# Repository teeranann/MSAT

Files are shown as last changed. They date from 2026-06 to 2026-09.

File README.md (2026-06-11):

# MSAT — Multi-Sensor Automatic Titrator

A low-cost, **ESP32-based open-hardware automatic acid–base titrator** with
gravimetric titrant delivery. It records **pH, electrical conductivity (EC),
colour change (ΔE), and temperature** simultaneously and in real time, serves a
live **WiFi dashboard**, and logs every run to an SD card. A companion desktop
**data analyzer** finds equivalence points (1st/2nd derivative + inflection
trendlines) and estimates titration enthalpy, and a **sync tool** copies runs
from the device to a PC.

> Copyright © 2026 **Burapha University**. Inventor/developer: **Teeranan Nongnual**.
> Co-inventors: **Nuttawisit Yasarawan, Pichamon Jittaviriyapong, Kanoksak Saelee, Akapong Suwattanamala, Supranee Kaewpirom, Takat Benjalersyarnon**.
> **Petty Patent pending — Application No. 2603001145** (filed 2026‑05‑12).
> Open source: Apache‑2.0 (code), CERN‑OHL‑S v2 (hardware), CC BY 4.0 (docs) — see [License](#license).

---

## Why MSAT?

Conventional manual burettes give discrete points and rely on subjective visual
endpoints. MSAT delivers titrant by mass (high precision), captures four sensor
channels continuously, and determines endpoints objectively across mono- and
polyprotic acid–base systems — at a fraction of the cost of commercial
autotitrators, suitable for teaching and research labs.

## Repository layout

| Folder | What it is |
|---|---|
| [`firmware/`](firmware/) | ESP32 Arduino firmware (`.ino`) — sensor acquisition, filtering, WiFi dashboard, SD logging |
| [`analyzer/`](analyzer/) | Python desktop app — load/analyze runs, EP detection, ΔT, live monitor |
| [`sync/`](sync/) | Windows + Git Bash tool — download runs from the device, clean up, protect folder |
| [`hardware/`](hardware/) | Wiring diagram, Fritzing sketch, component list |
| [`sample-data/`](sample-data/) | Example titration runs (one per acid) |
| [`docs/`](docs/) | Images and additional documentation |

## Quick start

1. **Build the device** — see [`hardware/`](hardware/) for wiring (ESP32 + ADS1115 pH,
   RS‑485/Modbus EC meter, GY‑33 colour, DS18B20 temperature, HX711 load cell, relay pump).
2. **Flash the firmware** — open [`firmware/msat-firmware/msat-firmware.ino`](firmware/),
   set your WiFi name/password (lines marked `EDIT ME`), install the required
   libraries, and upload. See [`firmware/README.md`](firmware/README.md).
3. **Open the dashboard** — browse to the device IP (default `192.168.1.200`) to
   start/monitor a titration live.
4. **Sync the data** — run [`sync/msat-sync.bat`](sync/) to copy runs to your PC.
5. **Analyze** — `pip install -r analyzer/requirements.txt` then
   `python analyzer/msat-datanal.py`. See [`analyzer/README.md`](analyzer/README.md).

## Key features

- **4 sensors in one run:** pH (ADS1115), EC (Modbus meter), colour ΔE (CIELAB/RGB), temperature (DS18B20)
- **Gravimetric titrant delivery** via load cell — endpoint by volume *or* mass
- **Real-time WiFi dashboard** (WebSocket) + on-device LCD
- **Auto-stop** by weight loss or time; SD logging of every run
- **Robust signal conditioning** (median + EMA + anomaly rejection) — clean curves, sharp inflections
- **Analyzer:** equivalence points (derivative + inflection trendlines), ΔT/enthalpy, glitch despike, live monitor via device WebSocket, batch export (PNG/TIFF/SVG/PDF) and config save/restore
- **Sync tool:** fast WiFi download, "clean up space" on the device, read-only folder protection

## License

This project is **open source / open hardware**:

- **Software** (firmware, analyzer, sync): **Apache License 2.0** — see [`LICENSE`](LICENSE)
- **Hardware** design files (schematic, wiring, BOM): **CERN‑OHL‑S v2** — see [`LICENSE-hardware`](LICENSE-hardware)
- **Documentation, images, sample data:** **CC BY 4.0**

You may **use, study, modify, distribute, and build upon** this work, **including for
commercial purposes**, under the terms of the applicable license (attribution required;
hardware derivatives must stay open under CERN‑OHL‑S). The petty patent
(Application No. 2603001145, Burapha University) is licensed under the patent grants of
these licenses. See [`NOTICE`](NOTICE).

## Citation

If you use MSAT in academic work, please cite it — see [`CITATION.cff`](CITATION.cff)
(a related manuscript is in preparation; cite the paper too once published).

## Author

**Teeranan Nongnual**<br>
Department of Chemistry, Faculty of Science, Burapha University, Thailand

## Funding

Burapha University (BUU) and Thailand Science Research and Innovation (TSRI).

## Acknowledgements

This software was developed with support from a research grant by Burapha
University and Thailand Science Research and Innovation (TSRI).

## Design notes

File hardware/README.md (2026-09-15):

# MSAT Hardware

Wiring and component information for building the MSAT device.

## Files
- `wiring/WIRING.md` — as-built connection table (power rails, level converter, pins) + part download links
- `wiring/msat-wiring.yml` — **WireViz source of truth** (pin-by-pin harness spec)
- `wiring/msat-wiring.html` — interactive harness diagram + BOM (open in browser)
- `wiring/msat-wiring.svg` / `.png` — rendered harness diagram (paper-grade)
- `wiring/msat-wiring.bom.tsv` — bill of materials (drops into Excel)
- `wiring/msat-wiring-schematic.svg` — high-level block diagram (overview figure)
- `wiring/msat-wiring-components.xlsx` — full wiring list and 30-line purchased BOM (same as Supplementary Tables S1 and S2)
- `wiring/msat-wiring.fzz` — Fritzing breadboard/schematic sketch (work-in-progress)
- `wiring/fritzing-parts/*.fzpz` — custom Fritzing parts
- `3d-print/msat-probe-lid.stl` — probe-mounting lid for the titration beaker (PETG)
- `3d-print/README.md` — print settings and material notes

To re-render the harness after editing the YAML:
```
pip install wireviz   # plus a system install of Graphviz (graphviz.org / winget install Graphviz.Graphviz)
wireviz wiring/msat-wiring.yml
```

## Main components
| Subsystem | Part | Interface |
|---|---|---|
| MCU | ESP32‑WROOM dev board | — |
| Power | 12 V / 5 A supply, LM2596 #1 (5 V bus), LM2596 #2 (pump, ~7.5 V) | — |
| pH | E‑201‑C electrode + analog interface board → ADS1115 16‑bit ADC (5 V) | I²C (0x48) via LLC‑4CH‑I2C level converter |
| EC | MI‑Water‑EC485 platinum‑black electrode + transmitter (12 V) | RS‑485 / Modbus via MAX485 |
| Colour | TCS34725 breakout (3.3 V) | I²C (0x29) |
| Temperature | DS18B20 probe | 1‑Wire (GPIO4) |
| Titrant mass | 200 g load cell + HX711 | GPIO25/26 |
| Pump | 12 V / 3 W peristaltic pump, relay‑switched | GPIO13 |
| Clock | DS3231 RTC (3.3 V) | I²C (0x68) |
| Display | 16×2 LCD, PCF8574 backpack (5 V) | I²C (0x27) |
| Storage | microSD | SPI (CS GPIO5) |

See [`../firmware/README.md`](../firmware/README.md) for the full pin map and
flashing notes (mind the GPIO2/GPIO15 strapping pins).

## Calibration
- **pH:** three‑point (pH 4.01 / 6.86 / 9.18 buffers, as stored in the firmware)
- **EC:** KCl standards across the working range
- **Load cell:** known‑mass calibration

---
Hardware design © 2026 Burapha University · CERN‑OHL‑S v2 · Patent pending No. 2603001145

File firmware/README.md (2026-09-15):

# MSAT Firmware (ESP32)

Arduino firmware for the MSAT device. Reads pH / EC / colour / temperature /
load cell, runs the titration state machine (IDLE → PENDING → RUNNING →
RINSING / REC), serves a WiFi dashboard + WebSocket telemetry, and logs every
run to the SD card.

## Board & toolchain
- **Board:** ESP32 (ESP32‑WROOM, e.g. ESP32‑D0WD‑V3)
- **Arduino‑ESP32 core** 3.x, Arduino IDE or arduino‑cli

## Required libraries (Library Manager)
- ESPAsyncWebServer + AsyncTCP (ESP32Async fork for core 3.x)
- Adafruit ADS1X15 (pH ADC)
- Adafruit TCS34725 (colour) *(GY‑33/TCS34725)*
- DallasTemperature + OneWire (DS18B20)
- HX711 (load cell)
- ModbusMaster (RS‑485 EC meter)
- RTClib (DS3231)
- LiquidCrystal_I2C (16×2 LCD)

## Pin map
| Function | Pin | Notes |
|---|---|---|
| I²C SDA / SCL | 32 / 33 | ADS1115 (pH 0x48, 5 V, through a 3.3 V ↔ 5 V level converter), TCS34725 (0x29), RTC (0x68), LCD (0x27) |
| RS‑485 DE/RE, RX, TX | 2, 16, 17 | EC meter (Modbus) — **GPIO2 is a strapping pin** |
| Load cell DOUT / SCK | 25 / 26 | HX711 |
| DS18B20 (1‑Wire) | 4 | temperature |
| SD card CS | 5 | SPI (VSPI) |
| Relay (pump) | 13 | titrant delivery |
| Buttons 1 / 2 / 3 | 27 / 14 / 15 | **GPIO15 is a strapping pin** |

> ⚠️ **Flashing:** GPIO2 and GPIO15 are ESP32 strapping pins. If wires are
> attached there during upload, flashing can fail — **disconnect them while
> flashing**, then reconnect.

## Configure before flashing
Edit the lines marked `EDIT ME` near the top of
`msat-firmware/msat-firmware.ino`:
```cpp
const char* ssid     = "YOUR_WIFI_SSID";       // 2.4 GHz network
const char* password = "YOUR_WIFI_PASSWORD";
#define ADMIN_PASSWORD "CHANGE_ME_BEFORE_USE"
```
The device uses a **static IP `192.168.1.200`** (gateway `192.168.1.1`) — change
`local_IP`/`gateway` if your network differs. After boot, open
`http://192.168.1.200/` for the dashboard.

> **Before you flash.** `ssid`, `password` and `ADMIN_PASSWORD` ship as placeholders and must be
> set to your own values. Do not commit real credentials: keep your edited copy local, or move the
> three values into a `secrets.h` that is listed in `.gitignore`.

## Sensor calibration
pH (3‑point: 4.01 / 6.86 / 9.18 buffers), EC (KCl standards), and load cell are calibrated via the
device/analyzer; see [`../hardware/`](../hardware/).

---
Copyright © 2026 Burapha University · Apache-2.0 · Patent pending No. 2603001145

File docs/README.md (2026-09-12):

# Documentation & images

Add device photos, dashboard screenshots, and example analyzed plots to
`images/` and reference them from the top‑level `README.md`.

Suggested images to add before publishing:
- `images/device.jpg` — the assembled MSAT instrument
- `images/dashboard.png` — live WiFi dashboard during a run
- `images/analyzer.png` — Data Analyzer with a titration + equivalence point
- `images/curve-example.png` — pH/EC/ΔE/T 4‑panel result

---
© 2026 Burapha University · CC BY 4.0

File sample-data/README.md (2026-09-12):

# Sample data

One representative titration run per acid (NaOH titrant). Load any `.txt` in
the Analyzer (`analyzer/`).

**These nine files are the exact runs the figures in the accompanying manuscript
were produced from**, so every published trace can be regenerated from this
folder.

| Acid | Run file | Figure panel source |
|---|---|---|
| KHP | `20260519_095745_KHP-3.txt` | `XO-20260519_095745_KHP-3` |
| HCl | `20260524_222410_HCl-12.txt` | `XO-20260524_222410_HCl-12` |
| H₂SO₄ | `20260524_224718_H2SO4-11.txt` | `XO-20260524_224718_H2SO4-11` |
| Oxalic | `20260525_145642_oxalic-12.txt` | `XO-20260525_145642_oxalic-12` |
| Phosphoric | `20260524_220156_phosphoric-15.txt` | `XO-20260524_220156_phosphoric-15` |
| Malic | `20260525_141012_malic-12.txt` | `XO-20260525_141012_malic-12` |
| Citric | `20260519_162855_Citric-12.txt` | `XO-20260519_162855_Citric-12` |
| Succinic | `20260521_102418_Succinic-17.txt` | `XO-20260521_102418_Succinic-17` |
| Benzoic | `20260521_154031_Benzoic-13.txt` | `XO-20260521_154031_Benzoic-13` |

All nine were recorded on the released firmware at a logging interval of
500 ms (2 Hz) and use the 13-column schema below.

## File format (CSV)
Header row, then one row per sample (500 ms apart):
```
SampleIndex,Timestamp,Temp,pH,Volt,EC,Weight,Weightloss,R,G,B,C,RelayStatus
```
| Column | Meaning | Unit |
|---|---|---|
| Temp | temperature | °C |
| pH | electrode pH | — |
| Volt | pH electrode voltage (amplified module output) | V |
| EC | conductivity | µS/cm |
| Weight / Weightloss | balance reading / titrant delivered | g |
| R,G,B,C | colour sensor channels | raw counts |
| RelayStatus | pump ON/OFF | — |

`Weightloss` (g) is the titrant axis (≈ mL at density 1.0).

Mass is recorded to two decimals, so the recording quantum is 10 mg; the
short-term repeatability of the mass channel in these runs is 5–6 mg.

pH is obtained by piecewise-linear interpolation between the three calibration
buffers (4.01 / 6.86 / 9.18), with linear extrapolation of the terminal segment
outside that range and a hard clamp to 0–14. Values above pH 9.18 are therefore
extrapolated.

## Acids included
KHP, HCl, H₂SO₄, oxalic, phosphoric, malic, citric, succinic, benzoic.

---
Data © 2026 Burapha University · CC BY 4.0

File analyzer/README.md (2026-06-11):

# MSAT Data Analyzer

Desktop app (Python + Tkinter/ttkbootstrap + matplotlib) to analyze MSAT runs.

## Install & run
```bash
pip install -r requirements.txt
python msat-datanal.py
```
Python 3.10+ recommended. `tkinterdnd2` is optional (drag‑and‑drop);
`websocket-client` enables the Live Monitor.

## What it does
- **Load a run** (`.txt`) via *Local File* or drag‑and‑drop; one‑shot load.
- **Derived curves:** pH (2‑point calibrated), colour ΔE (CIELAB or RGB),
  EC (auto µS/mS), temperature — plus 1st/2nd derivatives.
- **Equivalence points:** per‑sensor strategy (1st deriv. / 2nd deriv. /
  inflection trendlines); ΔT (enthalpy proxy).
- **Data processing:** auto "hiccup" despike (X‑axis glitch removal),
  Savitzky–Golay smoothing, click‑to‑delete a point, manual exclude.
- **Display:** per‑axis ranges, tick interval, point size/font, X in mL/mol/sec/g.
- **Live Monitor:** *Check MSAT* → *Live Monitor* listens to the device
  WebSocket (`ws://192.168.1.200/ws`) and plots the run in real time
  (seamless across multiple runs; UI locks until you Stop or load a file).
- **Export:** PNG/TIFF/SVG/PDF (filenames prefixed `-`) plus a
  `-<name>-config.txt` sidecar that restores all settings when the file is
  reopened.

## Notes
- Device default IP is `192.168.1.200` (edit `self.msat_ip` if changed).
- The high‑resolution record is the device SD file; Live Monitor is a coarse
  real‑time preview — sync the full file afterwards for detailed analysis.

---
Copyright © 2026 Burapha University · Apache-2.0 · Patent pending No. 2603001145

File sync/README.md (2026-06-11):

# MSAT Sync

Download titration runs from the MSAT device to a PC over WiFi, with optional
cleanup and folder protection. Windows front‑end (`msat-sync.bat`) drives the
worker (`msat-sync.sh`, runs under **Git Bash**).

## Requirements
- Windows + [Git for Windows](https://git-scm.com/download/win) (provides Git Bash)
- PC on the same WiFi as the device (default `192.168.1.200`)

## Use
Double‑click **`msat-sync.bat`** and pick from the menu:
```
[1] Sync files MSAT -> PC          (download new/updated runs)
[2] Clean up space on MSAT         (delete files older than N days)
[4] PROTECT MSAT-Output folder     (block accidental delete/rename)
[5] UNPROTECT MSAT-Output folder   (restore normal permissions)
[Q] Quit
```
- **Sync** writes runs into `MSAT-Output/` next to the script.
- **Cleanup** only deletes device files that are already backed up locally
  (size check) and older than the chosen days; you must type `DELETE` to confirm.
- **Protect** uses Windows `icacls` so files can be read/copied but not
  deleted/renamed (no admin needed — you own the folder).

## CLI flags (advanced)
`msat-sync.sh` accepts: `--mode=sync|cleanup|both`, `--cleanup-days=N`,
`--no-manifest` (default), `--unsafe-delete-unbacked`.

## How it gets the file list
The device exposes `/listfiles_raw?limit=all` (reads a cached index that the
firmware keeps current by appending each finished run). Sync downloads each
missing/updated file directly (no temp‑rename, so it works under folder
protection).

---
Copyright © 2026 Burapha University · Apache-2.0 · Patent pending No. 2603001145

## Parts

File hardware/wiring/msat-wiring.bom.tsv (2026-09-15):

Id | Description | Qty | Unit | Designators
1 | Cable, 1 wires | 0 | m | W_PUMP_SUPPLY
2 | Cable, 2 wires | 0 | m | I2C_HV_PWR, P_5V, P_BUCK1, P_BUCK2, P_EC, W_BTN1, W_BTN2, W_BTN3, W_PUMP
3 | Cable, 2 wires shielded | 0 | m | W_RS485_BUS
4 | Cable, 3 wires | 0 | m | A_PH, W_RELAY, W_TEMP
5 | Cable, 4 wires | 0 | m | I2C_ADS, I2C_GY33, I2C_LCD, I2C_LV, I2C_RTC, W_HX
6 | Cable, 6 wires | 0 | m | W_RS485_MCU, W_SD
7 | Connector, 12 V / 5 A (60 W) switching supply, main supply, 2 pins, black | 1 |  | PSU12V
8 | Connector, ADS1115 — pH ADC, I²C 0x48 (via level converter), 8 pins, blue | 1 |  | ADS1115
9 | Connector, DS18B20 — temperature probe, 1-Wire, 3 pins, green | 1 |  | DS18B20
10 | Connector, DS3231 RTC, I²C 0x68, 6 pins, blue | 1 |  | DS3231
11 | Connector, E-201-C pH electrode + analog interface board, analog out, 3 pins, blue | 1 |  | PHBOARD
12 | Connector, ESP32-WROOM-32 (38-pin), MCU, 19 pins, white | 1 |  | ESP32
13 | Connector, HX711 — load-cell amplifier, load cell, 8 pins, yellow | 1 |  | HX711
14 | Connector, LCD 16×2 + PCF8574 backpack, I²C 0x27, 5 V, 4 pins, blue | 1 |  | LCD1602
15 | Connector, LLC-4CH-I2C level converter, bidirectional 3.3 V ↔ 5 V, 8 pins, blue | 1 |  | LLC
16 | Connector, LM2596, 12 V → 5 V bus (lock at 5 V), 4 pins, black | 1 |  | BUCK1
17 | Connector, LM2596, 12 V → pump supply (~7.5 V), 4 pins, black | 1 |  | BUCK2
18 | Connector, MAX485 — RS-485 transceiver, Serial2 9600 8N1, 8 pins, orange | 1 |  | MAX485
19 | Connector, MI-Water-EC485 EC transmitter (Modbus RTU), slave id 1, holding reg 0x0000, 4 pins, orange | 1 |  | ECMETER
20 | Connector, Peristaltic pump 12 V / 3 W DC, run at ~7.5 V, 2 pins, red | 1 |  | PUMP
21 | Connector, Push button 1 (titration), 2 pins, grey | 1 |  | BTN1
22 | Connector, Push button 2 (rinse), 2 pins, grey | 1 |  | BTN2
23 | Connector, Push button 3 (record, strapping pin), 2 pins, grey | 1 |  | BTN3
24 | Connector, Relay 1-ch 5V (active-high), pump dosing, 6 pins, red | 1 |  | RELAY
25 | Connector, TCS34725 — colour, I²C 0x29, 6 pins, blue | 1 |  | GY33
26 | Connector, microSD card module, SPI (VSPI), 6 pins, violet | 1 |  | SDCARD

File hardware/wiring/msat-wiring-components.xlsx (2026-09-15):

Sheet: wiring
Category | Component | Library | Wiring / Connections | Note
1. Power System | 12 V / 5 A (60 W) switching power supply | - | • V+ (12V) ➡️ LM2596 #1 (IN+), LM2596 #2 (IN+), MI-Water-EC485 EC transmitter (Red) | Main power source split 3 ways
 |  |  | • V- (GND) ➡️ LM2596 #1 (IN-), LM2596 #2 (IN-), MI-Water-EC485 EC transmitter (Black), COMMON GROUND
 | LM2596 #1 (System 5V) | - | • IN+ ⬅️ 12V PSU (V+) | Step-down 12V to 5V for Board
 |  |  | • IN- ⬅️ 12V PSU (V-)
 |  |  | • OUT+ ➡️ 5V BUS (Powers ESP32, Relay Module, HX711, ADS1115, pH board, MAX485, SD, LCD) | **DO NOT ADJUST (Lock at 5V)**
 |  |  | • OUT- ➡️ COMMON GROUND
 | LM2596 #2 (Pump Flow) | - | • IN+ ⬅️ 12V PSU (V+) | **For Pump Speed Control (7.5V)**
 |  |  | • IN- ⬅️ 12V PSU (V-)
 |  |  | • OUT+ ➡️ Relay Module (COM Pin) | Adjust voltage to change Flow Rate
 |  |  | • OUT- ➡️ COMMON GROUND (or Pump Negative)
2. Processing | ESP32 (Dev Kit) | - | • VIN ⬅️ 5V BUS
 |  |  | • GND ⬅️ COMMON GROUND
 |  |  | • 3.3V ➡️ 3.3V BUS (Powers RTC, Color, Temp)
 |  |  | • GPIO 32/33 ➡️ I2C Bus (ADS1115 via level converter, TCS34725, DS3231, LCD)
 |  |  | • GPIO 18/19/23/5 ➡️ SD Card (SPI)
 |  |  | • GPIO 16/17/2 ➡️ RS485
 |  |  | • GPIO 13 ➡️ Relay (Trigger)
 |  |  | • GPIO 27/14/15 ➡️ Buttons
 |  |  | • GPIO 25/26 ➡️ Load Cell
 |  |  | • GPIO 4 ➡️ Temp Sensor
3. Interface | LLC-4CH-I2C (bidirectional logic-level converter, 5 V / 3.3 V) | - | [LV Side - 3.3V] | I2C Level Shifting for ADS1115
 |  |  | • LV ⬅️ 3.3V BUS | GND ⬅️ GND
 |  |  | • LV1 ⬅️ ESP32 (D33 SCL) | LV2 ⬅️ ESP32 (D32 SDA)
 |  |  | [HV Side - 5V]
 |  |  | • HV ⬅️ 5V BUS | GND ⬅️ GND
 |  |  | • HV1 ➡️ ADS1115 (SCL) | HV2 ➡️ ADS1115 (SDA)
 | MAX485 (RS485) | ModbusMaster | • VCC ⬅️ 5V BUS | Signal Converter for EC
 |  |  | • GND ⬅️ GND
 |  |  | • DI ⬅️ ESP32 (D17 TX2)
 |  |  | • RO ➡️ ESP32 (D16 RX2)
 |  |  | • DE/RE ⬅️ ESP32 (D2)
 |  |  | • A, B ➡️ MI-Water-EC485 EC transmitter (Yellow/Blue wires)
4. Data/Time | Micro SD Card Module | SPI, SD | • VCC ⬅️ 5V BUS | Data Logging
 |  |  | • GND ⬅️ GND
 |  |  | • CS ⬅️ GPIO 5
 |  |  | • SCK ⬅️ GPIO 18
 |  |  | • MISO ⬅️ GPIO 19
 |  |  | • MOSI ⬅️ GPIO 23
 | DS3231 (RTC) | RTClib | • VCC ⬅️ 3.3V BUS, GND ⬅️ GND | Real Time Clock
 |  |  | • SDA ⬅️ GPIO 32, SCL ⬅️ GPIO 33
 | LCD 1602 + PCF8574 (I2C display) | LiquidCrystal_I2C | • VCC ⬅️ 5V BUS, GND ⬅️ GND | Local status display (I2C 0x27)
 |  |  | • SDA ⬅️ GPIO 32, SCL ⬅️ GPIO 33 (direct, not through the level converter) | As built. For a new build, use the converter HV side or remove the backpack pull-ups
5. Sensors | ADS1115 (ADC for pH) | Adafruit ADS1X15 | • VDD ⬅️ 5V BUS, GND ⬅️ GND | High Precision Analog Read
 |  |  | • SCL ⬅️ LLC-4CH-I2C (HV1)
 |  |  | • SDA ⬅️ LLC-4CH-I2C (HV2)
 |  |  | • A0 ⬅️ pH interface board (PO)
 | E-201-C pH electrode + analog interface board | - | • VCC ⬅️ 5V BUS, GND ⬅️ GND, PO ➡️ ADS1115(A0)
 | HX711 + Load Cell | HX711 | • VCC ⬅️ 5V BUS, GND ⬅️ GND | Weight Scale
 |  |  | • DT ➡️ GPIO 25, SCK ⬅️ GPIO 26
 | TCS34725 color-sensor breakout | Adafruit TCS34725 | • VIN ⬅️ 3.3V BUS, GND ⬅️ GND | Color Sensor
 |  |  | • SDA ➡️ GPIO 32, SCL ⬅️ GPIO 33
 | DS18B20 (Temp) | DallasTemperature | • VCC ⬅️ 3.3V BUS, GND ⬅️ GND | Temperature Sensor
 |  |  | • DATA ➡️ GPIO 4 (Requires 4.7k Pull-up Resistor)
6. Pump Control | Relay Module (1 Channel) | - | [Control Side - To ESP32] | Switch Pump ON/OFF
 |  |  | • VCC ⬅️ 5V BUS
 |  |  | • GND ⬅️ GND
 |  |  | • IN ⬅️ GPIO 13
 |  |  | [High Power Side - Pump Power]
 |  |  | • COM ⬅️ LM2596 #2 (OUT+) | **Power from Buck #2**
 |  |  | • NO ➡️ Pump Red (+) | Connects power when ON
 | Peristaltic pump (12 V / 3 W, 2-17 mL/min) | - | • Red Wire (+) ⬅️ Relay NO | Pump (Running at ~7.5V)
 |  |  | • Black Wire (-) ➡️ COMMON GROUND
7. Buttons | Buttons (x3) | - | • Pin 1 ➡️ GPIO 27 / 14 / 15 | Start / Rinse / Rec
 |  |  | • Pin 2 ➡️ GND

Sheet: components
Item No. | Product Code | Description | Country of Origin | Qty | Unit Cost (THB) | Unit Cost (USD) | Cost (USD)
1 | ESP-WROOM-32 | ESP32-WROOM-32 development board (38-pin) | China (Espressif Systems, Shanghai) | 1 | 194
2 | S-60-12 type | 12 V / 5 A (60 W) switching power supply | Thailand (AEI.th, Bangkok) | 1 | 130
3 | LM2596-ADJ | LM2596 adjustable buck converter (5 V bus and pump supply) | China | 2 | 40
4 | SD-TF-SPI | microSD card module (SPI) | China | 1 | 17
5 | - | microSD card, 16 GB | China | 1 | 120
6 | DS3231-RTC | DS3231 real-time-clock module (I2C) | China | 1 | 60
7 | LCD1602A-I2C | LCD 16 × 2 character display with PCF8574 I2C backpack | Thailand (ModuleMore) | 1 | 99
8 | HX711-200G-KIT | Strain-gauge load cell, 200 g, with HX711 24-bit amplifier | China | 1 | 265
9 | E-201-C | E-201-C glass combination pH electrode with analog interface board | Thailand (AEI.th, Bangkok) | 1 | 278
10 | DS18B20-WP | DS18B20 waterproof digital temperature probe | China | 1 | 48
11 | TCS34725-RGB | TCS34725 color sensor module (sensor die: ams-OSRAM AG, Austria) | Thailand (O.R. Technology, Bangkok) | 1 | 120
12 | MI-Water-EC485 | Platinum-black conductivity electrode with RS-485 Modbus transmitter | China (supplied by Miniature Innovation Solution Co., Ltd., Thailand) | 1 | 2852
13 | MAX485-TTL | MAX485 TTL-to-RS-485 transceiver module | China | 1 | 15
14 | LLC-4CH-I2C | Bidirectional I2C logic-level converter, 5 V / 3.3 V (ADS1115 bus) | China | 1 | 29
15 | ADS1115-I2C | ADS1115 16-bit ADC module (Texas Instruments, USA) | China | 1 | 117
16 | RELAY-5V-1CH | Relay module, 1 channel, 5 V | China | 1 | 26
17 | BTN-TACT-12MM | Tactile push button, 12 mm | China | 3 | 10
18 | PUMP-PERIST-12V | Peristaltic pump, 12 V / 3 W, 2–17 mL/min (run at ~7.5 V via LM2596 #2) | Thailand (ModuleMore) | 1 | 220
19 | - | Dupont jumper wire set (40 pieces) | Thailand (retail) | 1 | 45
20 | - | Screw terminals and lever connectors | Thailand (retail) | 1 | 60
21 | - | Solder wire | Thailand (retail) | 1 | 60
22 | - | M3 screws, nuts and standoffs | Thailand (retail) | 1 | 50
23 | - | Silicone tubing, 1.0 × 3.0 mm, 1 m | Thailand (retail) | 1 | 40
24 | - | Titrant bottle, 250 mL, with cap | Thailand (retail) | 1 | 40
25 | - | Expanded-polystyrene calorimeter enclosure | Thailand (retail) | 1 | 30
26 | - | Heat-shrink tubing assortment | Thailand (retail) | 1 | 30
27 | - | DC barrel jack and mains lead | Thailand (retail) | 1 | 25
28 | - | PETG filament for the 3D-printed probe lid (~10 g) | Thailand (retail) | 1 | 20
29 | - | Prototyping perfboard, 7 × 9 cm | Thailand (retail) | 1 | 15
30 | - | Passive components (4.7 kΩ pull-up, decoupling capacitors) | Thailand (retail) | 1 | 10
 |  |  |  |  |  | TOTAL:
Prices as purchased (components) or typical Thai retail (lines 19-30), converted at 32.43 THB per USD. Identical to Supplementary Table S1; total THB 5,125 = USD 158.03.

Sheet: libraries
Library | Author | Usage / Purpose
OneWire | Paul Stoffregen | Communication protocol for DS18B20
DallasTemperature | Miles Burton | Reading temperature data
HX711_ADC | Olav Kallhovd | Reading Load Cell weight data
Wire | Arduino | I2C Communication (ESP32 Built-in)
SPI | Arduino | SPI Communication (ESP32 Built-in)
SD | Arduino | SD Card file management
Adafruit ADS1X15 | Adafruit | Controlling ADS1115 (High prec. ADC for pH)
Adafruit TCS34725 | Adafruit | Reading Color Sensor data
RTClib | Adafruit | Controlling DS3231/DS1307 RTC
ModbusMaster | 4-20ma.io | Communication with EC Sensor (RS485)
WebServer | Arduino | Creating Web Interface (ESP32 Built-in)
LiquidCrystal_I2C | Frank de Brabander | 16×2 LCD with PCF8574 I2C backpack

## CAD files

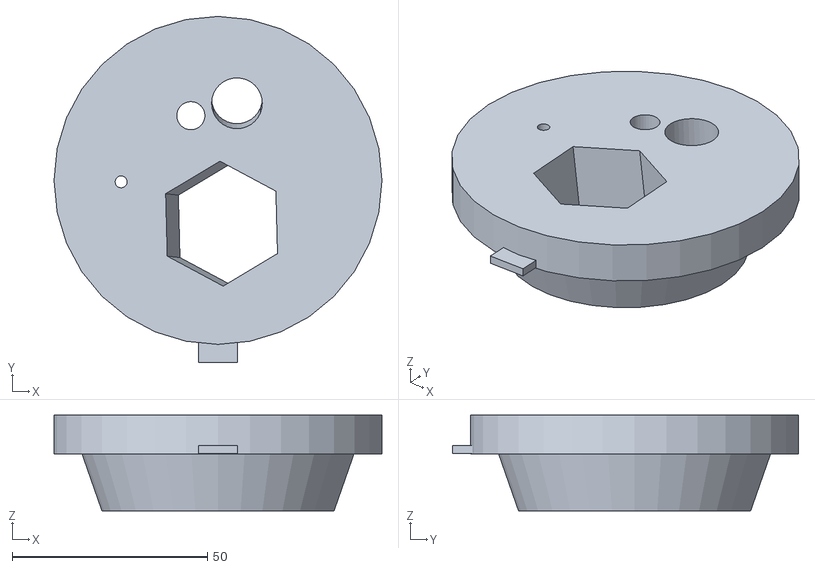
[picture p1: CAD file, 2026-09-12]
hardware/3d-print/msat-probe-lid.stl
84.0 x 88.7 x 24.5

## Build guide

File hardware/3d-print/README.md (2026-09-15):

# 3D-printed parts

| File | Part | Triangles | Notes |
|---|---|---:|---|
| `msat-probe-lid.stl` | Probe-mounting lid for the 250 mL titration beaker | 710 | Holds the four probes (pH electrode, conductivity electrode, DS18B20 temperature probe and the titrant delivery tube) in fixed positions over the analyte, and closes the beaker inside the calorimeter enclosure. |

The lid has four openings: a large round hole for the pH electrode, a hexagonal seat for the
conductivity electrode's gland nut, a smaller round hole for the DS18B20 probe and a narrow hole for
the titrant delivery tube.

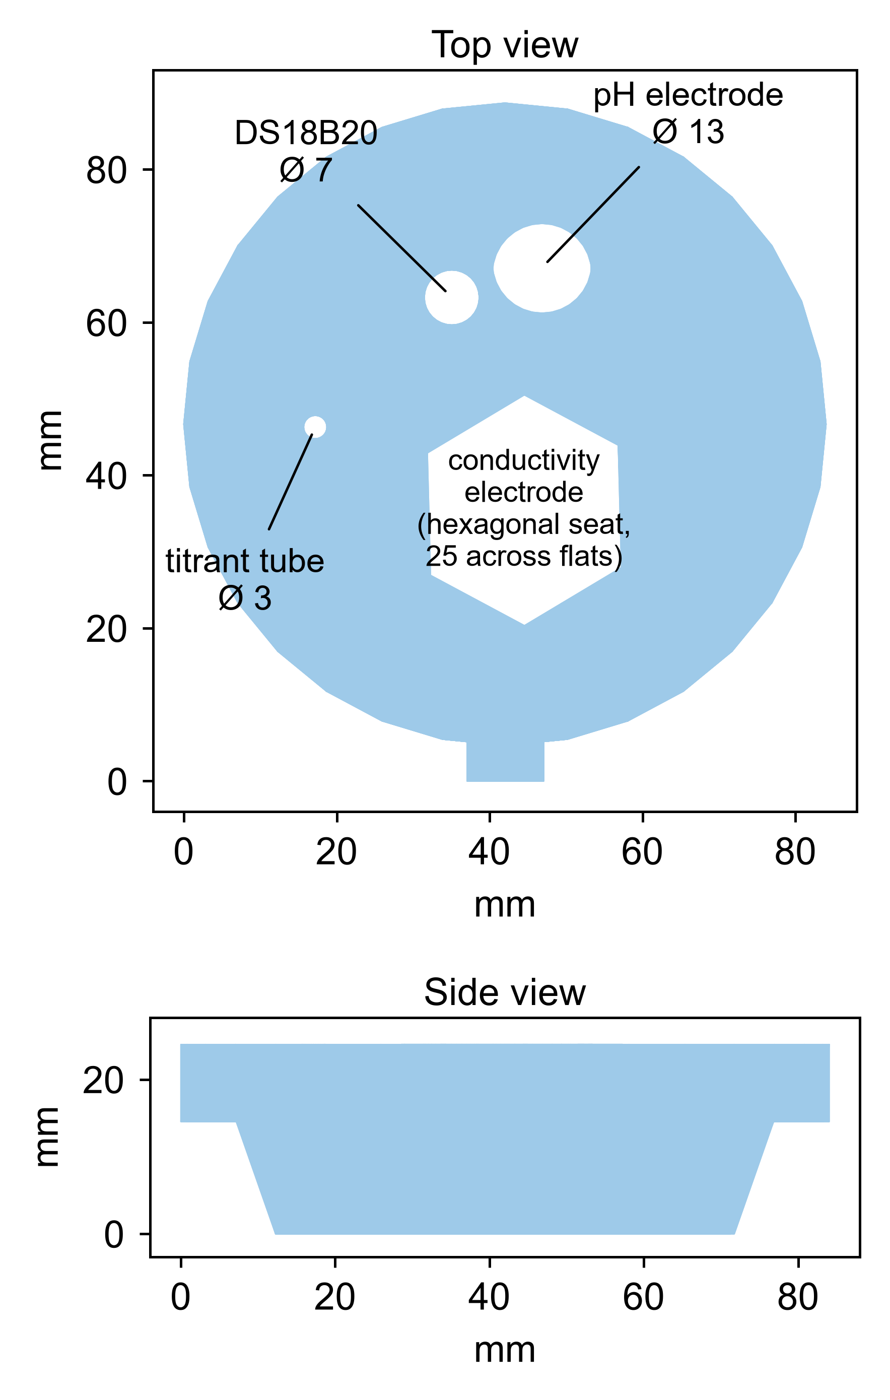
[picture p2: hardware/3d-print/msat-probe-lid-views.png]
Top and side views of the probe lid, drawn from the STL


The TCS34725 color sensor is **not** part of the lid and has no printed mount. It is fixed with
adhesive tape to the inner wall of the expanded-polystyrene calorimeter enclosure, pressed against
the outside of the beaker, and a white LED panel on the opposite side of the beaker shines through
the solution toward it.

## Printing

Printed on a Bambu Lab P2S (Bambu Lab, Shenzhen, China) and sliced with Bambu Studio.

| Setting | Value |
|---|---|
| Material | PETG |
| Approximate material use | 10 g |

PETG was chosen for its chemical resistance to dilute acids, bases and ethanol, and for its
dimensional stability at the temperatures reached during a thermometric titration. PLA is not
recommended: it softens well below the temperatures seen in the enclosure and is attacked by
ethanol.

Any fused-filament printer with a 256 mm build volume or larger will produce this part; the
specific printer and slicer are recorded only so the published result can be reproduced exactly.

---
Hardware design © 2026 Burapha University · CERN-OHL-S v2 · Patent pending No. 2603001145

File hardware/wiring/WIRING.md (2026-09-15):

# MSAT Wiring (as built)

Connection spec for the instrument that produced the published data. Pin numbers
are ESP32 GPIO numbers and match the `#define`s in
[`../../firmware/msat-firmware/msat-firmware.ino`](../../firmware/msat-firmware/msat-firmware.ino);
supply rails and the I²C level converter are taken from the built unit, which the
firmware cannot show. This file, `msat-wiring.yml` and
`msat-wiring-components.xlsx` agree with Supplementary Table S2 of the paper.

> ⚠️ **Strapping pins:** GPIO2 (MAX485 DE/RE) and GPIO15 (Button 3) are ESP32
> strapping pins — disconnect them while flashing, then reconnect.

## Power
| Source | Feeds |
|---|---|
| 12 V / 5 A (60 W) switching supply | LM2596 #1, LM2596 #2, MI-Water-EC485 EC transmitter (red V+, black GND) |
| LM2596 #1 — **5 V bus** (lock at 5 V) | ESP32 VIN, ADS1115, pH interface board, HX711, MAX485, microSD module, relay module, LCD, level-converter HV side |
| LM2596 #2 — **pump supply** (~7.5 V, sets the flow rate) | relay COM → pump |
| ESP32 on-board regulator — **3.3 V bus** | DS3231, TCS34725, DS18B20, level-converter LV side |

All grounds are common.

## I²C bus — SDA = GPIO32, SCL = GPIO33
`Wire.begin(32, 33)`.

| Device | Part | Address | Supply | Bus connection |
|---|---|---|---|---|
| pH ADC | ADS1115 (16-bit) | 0x48 | **5 V** | **through the level converter (HV side)** |
| Colour | TCS34725 breakout | 0x29 | 3.3 V | direct to GPIO32 / GPIO33 |
| RTC | DS3231 | 0x68 | 3.3 V | direct to GPIO32 / GPIO33 |
| Display | LCD 16×2 (PCF8574 backpack) | 0x27 | **5 V** | direct to GPIO32 / GPIO33 |

### Level converter — LLC-4CH-I2C (bidirectional, 3.3 V ↔ 5 V)
| Side | Pin | Connection |
|---|---|---|
| LV (3.3 V) | LV / GND | 3.3 V bus / GND |
| LV | LV1 / LV2 | ESP32 GPIO33 (SCL) / GPIO32 (SDA) |
| HV (5 V) | HV / GND | 5 V bus / GND |
| HV | HV1 / HV2 | ADS1115 SCL / SDA |

> ⚠️ **If you build a copy:** the LCD backpack runs at 5 V and is wired straight to
> GPIO32/33, so its on-board pull-up resistors pull the I²C lines towards 5 V,
> above the ESP32's 3.3 V pin rating. The original unit works this way, but for a
> new build either connect the LCD to the HV side of the level converter alongside
> the ADS1115, or remove the pull-ups on the PCF8574 backpack.

## pH front-end
| From | To |
|---|---|
| E-201-C glass combination electrode (BNC) | analog pH interface board |
| pH interface board VCC / GND | 5 V / GND |
| pH interface board PO | ADS1115 AIN0 (single-ended) |
| ADS1115 VDD / GND | 5 V / GND |
| ADS1115 SCL / SDA | level converter HV1 / HV2 |

## EC meter — RS-485 / Modbus (`Serial2` 9600 8N1, slave id 1)
| ESP32 | MAX485 | Notes |
|---|---|---|
| GPIO2 | DE + RE (tied) | `MAX485_DE_RE`, strapping pin |
| GPIO16 (RX) | RO | `MAX485_RX` |
| GPIO17 (TX) | DI | `MAX485_TX` |
| 5V / GND | VCC / GND | |
| — | A / B → MI-Water-EC485 transmitter (yellow / blue) | reads holding register 0x0000 |

The EC transmitter itself is powered from the 12 V supply (red V+, black GND).

## Temperature — DS18B20 (1-Wire)
| Signal | Pin | Notes |
|---|---|---|
| DQ (data) | GPIO4 | `ONE_WIRE_BUS`, 4.7 kΩ pull-up to 3V3 |
| VDD / GND | 3V3 / GND | |

## Titrant mass — HX711 + load cell
| HX711 | ESP32 |
|---|---|
| DOUT | GPIO25 (`LOADCELL_DOUT_PIN`) |
| SCK | GPIO26 (`LOADCELL_SCK_PIN`) |
| VCC / GND | 5V / GND |
| E+/E-/A+/A- | load cell bridge wires |

## microSD — SPI (VSPI defaults)
| Signal | Pin |
|---|---|
| CS | GPIO5 (`SD_CS_PIN`) |
| SCK | GPIO18 |
| MISO | GPIO19 |
| MOSI | GPIO23 |
| VCC / GND | 5V / GND |

## Pump relay
| Signal | Connection |
|---|---|
| Relay IN | GPIO13 (`RELAY_PIN`) |
| VCC / GND | 5V / GND |
| COM | LM2596 #2 OUT+ |
| NO | pump red (+) |
| Pump black (−) | common ground |

*Single 1-channel 5 V relay module (active-high). The pump is a 12 V / 3 W DC
peristaltic pump run at about 7.5 V from LM2596 #2. Not a WeMos shield.*

## Buttons (to GND, internal pull-ups)
| Button | Pin | Notes |
|---|---|---|
| Button 1 | GPIO27 (`BUTTON1_PIN`) | start / stop titration |
| Button 2 | GPIO14 (`BUTTON2_PIN`) | start / stop rinse |
| Button 3 | GPIO15 (`BUTTON3_PIN`) | record-only logging; strapping pin |

---

## Sketch fix checklist (`msat-wiring.fzz`)
The current sketch needs the following to match the wiring above:

**Remove**
- [ ] Both *WeMos D1-Mini Relay Shield* parts (wrong form factor for ESP32).

**Add**
- [ ] 12 V supply and a second LM2596 (pump supply).
- [ ] LLC-4CH-I2C level converter between GPIO32/33 and the ADS1115; power the ADS1115 from 5 V.
- [ ] 1× 1-channel 5V relay module → GPIO13, COM from LM2596 #2.
- [ ] DS3231 RTC → I²C (0x68).
- [ ] LCD 16×2 I²C → I²C (0x27), 5 V.
- [ ] microSD card module → VSPI, CS GPIO5.
- [ ] 2 more push buttons (duplicate the existing one) → GPIO14, GPIO15.
- [ ] EC transmitter on the MAX485 A/B lines, powered from 12 V.
- [ ] pH electrode and interface board into ADS1115 AIN0.

**Already present & correct:** ESP32-38pin, ADS1115, GY-33, DS18B20, HX711,
MAX485, LM2596, 1× push button.

**After editing:** `File ▸ Save` in Fritzing so all parts re-embed into the
`.fzz` (this keeps the file portable on other machines).

## Fritzing parts to download
Already bundled in `fritzing-parts/`: ADS1115, DS18B20, GY-33, WAGO.
Still needed — download the `.fzpz`, then in Fritzing use **Part ▸ Import…**,
place + wire per the tables above, and **File ▸ Save** (re-embeds everything):

| Module | Source (`.fzpz`) |
|---|---|
| DS3231 RTC | [Soldered/e-radionica library](https://github.com/SolderedElectronics/e-radionica.com-Fritzing-Library-parts-/blob/master/DS3231%20RTC.fzpz) · [Adafruit](https://github.com/adafruit/Fritzing-Library/blob/master/parts/Adaruit%20DS3231.fzpz) · core part `rtc_ds3231_breakout` |
| LCD 16×2 I²C | [johnyHV LCD1602-I2C](https://github.com/johnyHV/fritzing-parts/blob/master/LCD1602-I2C.fzpz) · [Soldered "LCD screen 16x2 IIC"](https://github.com/SolderedElectronics/e-radionica.com-Fritzing-Library-parts-/blob/master/LCD%20screen%2016x2%20IIC.fzpz) |
| microSD module | [coderfls "Catalex MicroSD Module"](https://github.com/coderfls/Fritzing-Parts/blob/main/Catalex%20MicroSD%20Module.fzpz) · [robertoostenveld "SD Card Module"](https://github.com/robertoostenveld/fritzing/blob/master/SD%20Card%20Module.fzpz) |
| 1-channel 5V relay | [coderfls "5V Relay Module"](https://github.com/coderfls/Fritzing-Parts/blob/main/5V%20Relay%20Module.fzpz) · [KY-019](https://github.com/coderfls/Fritzing-Parts/blob/main/KY-019%205V%20Relay%20Module.fzpz) |
| MAX485 / RS-485 | [Warlib1975 "RS485 module MAX485"](https://github.com/Warlib1975/Fritzing-parts/blob/master/RS485%20module%20MAX485.fzpz) (SparkFun MAX485 also in Fritzing core) |
| Level converter | Fritzing core part "Logic Level Converter" (SparkFun BOB-12009), 4 channels |
| pH probe + board | label a generic 2-terminal BNC input on a generic analog board feeding ADS1115 AIN0 |
| EC transmitter | use a labelled generic sensor on the MAX485 A/B lines (no standard part) |

> On GitHub, open the file and click **Download raw file** to get the `.fzpz`.

## Quick reference figure
`msat-wiring-schematic.svg` is a high-level block diagram of the wiring above.

## Detailed harness diagram (WireViz)
`msat-wiring.yml` is the WireViz source of truth: every connector with every
pin, every cable with explicit pin-to-pin connections, colour-coded by bus.
Rendered outputs in this folder:

- `msat-wiring.html` — interactive viewer with embedded BOM (open in browser)
- `msat-wiring.svg` / `msat-wiring.png` — harness diagram
- `msat-wiring.bom.tsv` — connector and cable list

Re-render after editing the YAML:
```
pip install wireviz                            # one-time
winget install Graphviz.Graphviz               # one-time (system, needs `dot`)
wireviz msat-wiring.yml                         # produces .html/.svg/.png/.bom.tsv
```

`msat-wiring-components.xlsx` holds the full wiring list and the purchased bill
of materials (30 lines, THB and USD at 32.43 THB per USD), identical to
Supplementary Tables S1 and S2.

---
Hardware design © 2026 Burapha University · CERN-OHL-S v2 · Patent pending No. 2603001145

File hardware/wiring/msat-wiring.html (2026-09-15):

# MSAT — ESP32-WROOM-32 wiring (as built)

## Diagram

Multi-Sensor Automatic Titrator. 12 V supply with two LM2596 bucks (5 V bus and pump supply). ESP32 talks to four I²C devices: ADS1115/pH at 5 V through an LLC-4CH-I2C level converter, TCS34725/colour and DS3231 RTC at 3.3 V, and a 16×2 LCD at 5 V. One 1-Wire DS18B20, HX711 load cell, MAX485 → Modbus EC transmitter, microSD on VSPI, a pump relay, and three push buttons.

## Bill of Materials

Id | Description | Qty | Unit | Designators
1 | Cable, 1 wires | 0 | m | W_PUMP_SUPPLY
2 | Cable, 2 wires | 0 | m | I2C_HV_PWR, P_5V, P_BUCK1, P_BUCK2, P_EC, W_BTN1, W_BTN2, W_BTN3, W_PUMP
3 | Cable, 2 wires shielded | 0 | m | W_RS485_BUS
4 | Cable, 3 wires | 0 | m | A_PH, W_RELAY, W_TEMP
5 | Cable, 4 wires | 0 | m | I2C_ADS, I2C_GY33, I2C_LCD, I2C_LV, I2C_RTC, W_HX
6 | Cable, 6 wires | 0 | m | W_RS485_MCU, W_SD
7 | Connector, 12 V / 5 A (60 W) switching supply, main supply, 2 pins, black | 1 | | PSU12V
8 | Connector, ADS1115 — pH ADC, I²C 0x48 (via level converter), 8 pins, blue | 1 | | ADS1115
9 | Connector, DS18B20 — temperature probe, 1-Wire, 3 pins, green | 1 | | DS18B20
10 | Connector, DS3231 RTC, I²C 0x68, 6 pins, blue | 1 | | DS3231
11 | Connector, E-201-C pH electrode + analog interface board, analog out, 3 pins, blue | 1 | | PHBOARD
12 | Connector, ESP32-WROOM-32 (38-pin), MCU, 19 pins, white | 1 | | ESP32
13 | Connector, HX711 — load-cell amplifier, load cell, 8 pins, yellow | 1 | | HX711
14 | Connector, LCD 16×2 + PCF8574 backpack, I²C 0x27, 5 V, 4 pins, blue | 1 | | LCD1602
15 | Connector, LLC-4CH-I2C level converter, bidirectional 3.3 V ↔ 5 V, 8 pins, blue | 1 | | LLC
16 | Connector, LM2596, 12 V → 5 V bus (lock at 5 V), 4 pins, black | 1 | | BUCK1
17 | Connector, LM2596, 12 V → pump supply (~7.5 V), 4 pins, black | 1 | | BUCK2
18 | Connector, MAX485 — RS-485 transceiver, Serial2 9600 8N1, 8 pins, orange | 1 | | MAX485
19 | Connector, MI-Water-EC485 EC transmitter (Modbus RTU), slave id 1, holding reg 0x0000, 4 pins, orange | 1 | | ECMETER
20 | Connector, Peristaltic pump 12 V / 3 W DC, run at ~7.5 V, 2 pins, red | 1 | | PUMP
21 | Connector, Push button 1 (titration), 2 pins, grey | 1 | | BTN1
22 | Connector, Push button 2 (rinse), 2 pins, grey | 1 | | BTN2
23 | Connector, Push button 3 (record, strapping pin), 2 pins, grey | 1 | | BTN3
24 | Connector, Relay 1-ch 5V (active-high), pump dosing, 6 pins, red | 1 | | RELAY
25 | Connector, TCS34725 — colour, I²C 0x29, 6 pins, blue | 1 | | GY33
26 | Connector, microSD card module, SPI (VSPI), 6 pins, violet | 1 | | SDCARD

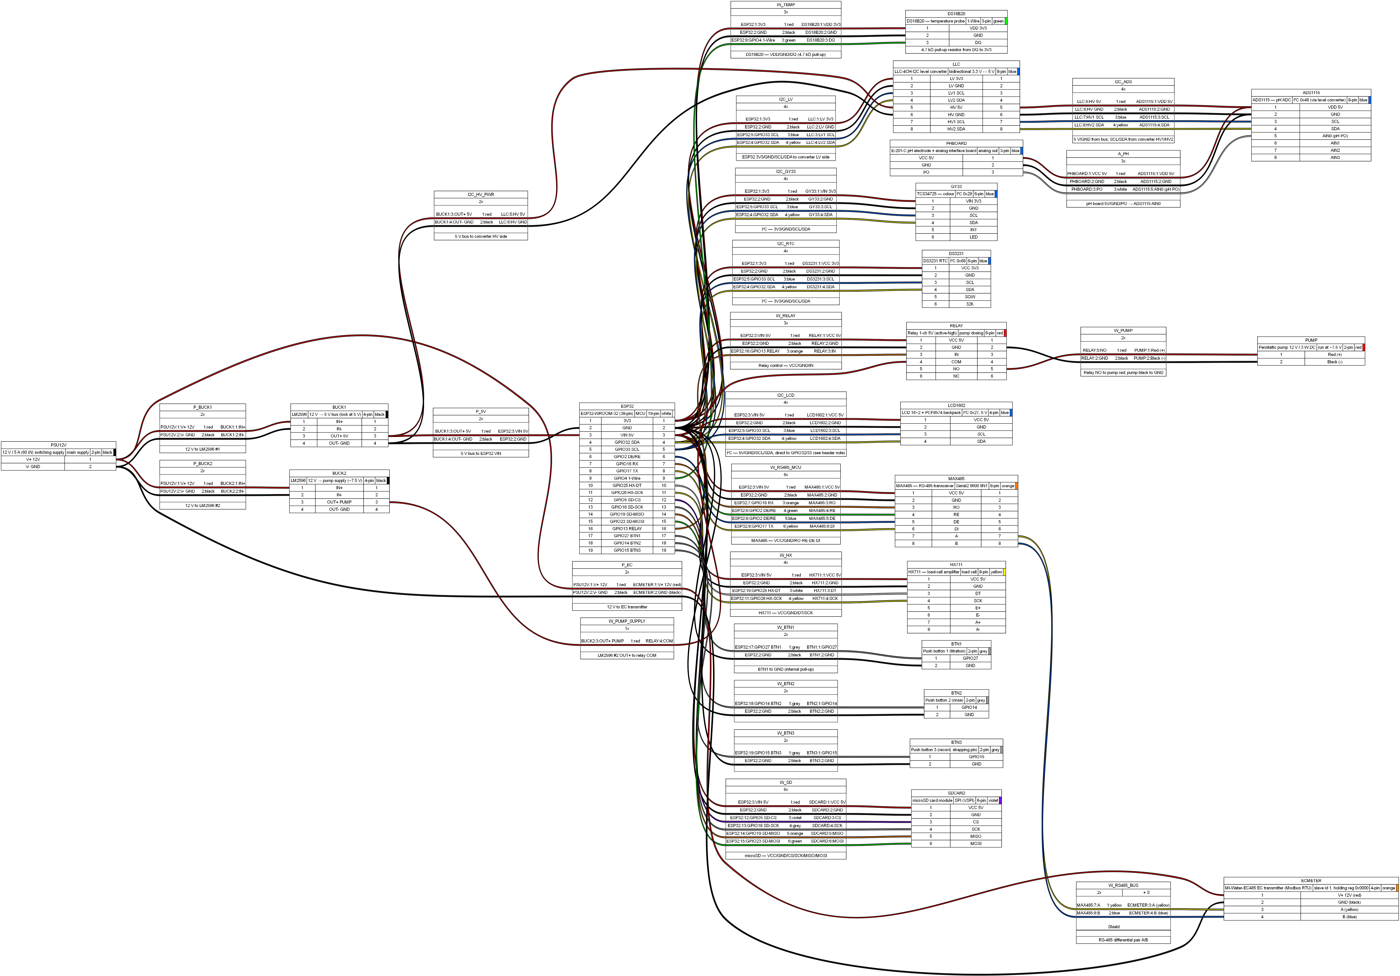
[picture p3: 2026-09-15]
hardware/wiring/msat-wiring.png

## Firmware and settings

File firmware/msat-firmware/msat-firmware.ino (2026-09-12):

/*
 * ============================================================================
 * MSAT Controller - Multi-Sensor Automatic Titrator   (firmware V.Y2026.88.17)
 * ----------------------------------------------------------------------------
 * ESP32 firmware for a low-cost automatic acid-base titrator that logs pH,
 * electrical conductivity (EC), colour (RGB -> dE), temperature and titrant
 * mass in real time, serves a WiFi dashboard, and saves runs to an SD card.
 *
 * Copyright (c) 2026 Burapha University.
 * Inventor / developer: Teeranan Nongnual <teeranan.no@buu.ac.th>
 *   Department of Chemistry, Faculty of Science, Burapha University, Thailand
 *
 * Petty Patent pending: Application No. 2603001145 (filed 2026-05-12).
 *
 * License: Apache License 2.0  (see /LICENSE). Free for any use, including
 *   commercial, with attribution. The petty patent above is licensed under
 *   Apache-2.0 section 3.
 * SPDX-License-Identifier: Apache-2.0
 * Required Notice: Copyright (c) 2026 Burapha University.
 *
 * SETUP: set your WiFi name/password in the two lines marked "EDIT ME" below.
 * ============================================================================
 */

#include <WiFi.h>
#include <ESPAsyncWebServer.h>
#include <AsyncWebSocket.h>
#include <SPI.h>
#include <SD.h>
#include <OneWire.h>
#include <DallasTemperature.h>
#include <time.h>
#include <sys/time.h> 
#include <Wire.h>
#include "HX711.h"
#include <Adafruit_ADS1X15.h>
#include <Adafruit_TCS34725.h>
#include <ModbusMaster.h>
#include <RTClib.h> 
#include <LiquidCrystal_I2C.h> 
#include <vector>
#include <algorithm>
#include <deque>
#include <esp_task_wdt.h>
#include "soc/soc.h"
#include "soc/rtc_cntl_reg.h"

#ifndef ON
#define ON true
#endif
#ifndef OFF
#define OFF false
#endif

#define EC_PROFILE_CONSERVATIVE 0
#define EC_PROFILE_BALANCED 1
#define EC_PROFILE_AGGRESSIVE 2

// ================= USER PIN & WIFI CONFIGURATION =================
const char* ssid     = "YOUR_WIFI_SSID";       // <-- EDIT ME (2.4 GHz network)
const char* password = "YOUR_WIFI_PASSWORD";   // <-- EDIT ME
IPAddress local_IP(192, 168, 1, 200);
IPAddress gateway(192, 168, 1, 1);
IPAddress subnet(255, 255, 255, 0);
IPAddress primaryDNS(8, 8, 8, 8);
IPAddress secondaryDNS(8, 8, 4, 4);

// ================= USER SENSOR CONFIGURATION =================
const bool ECadaptivefilter = ON;
const uint8_t ECadaptiveProfile = EC_PROFILE_BALANCED;

// ================= USER WEB DASHBOARD CONFIGURATION =================
const unsigned long WS_REFRESH_IDLE_MS = 1000;
const unsigned long WS_REFRESH_RUN_REC_MS = 500;
const unsigned long WS_REFRESH_PENDING_RINSE_MS = 1000;

#define RELAY_PIN 13
#define MAX485_DE_RE 2
#define MAX485_RX 16
#define MAX485_TX 17
#define BUTTON1_PIN 27
#define BUTTON2_PIN 14
#define BUTTON3_PIN 15
#define I2C_SDA 32
#define I2C_SCL 33
#define LOADCELL_DOUT_PIN 25
#define LOADCELL_SCK_PIN 26
#define SD_CS_PIN 5
#define SD_SPI_FREQ 4000000
#define ONE_WIRE_BUS 4

// ================= CALIBRATION DATA =================
float ph_voltages[] = { 4.3066, 3.9333, 3.5657 }; 
float ph_values[]   = { 4.01,   6.86,   9.18 };

float cal_ec_raw[] = { 80.08, 1400.51, 12387.90 }; 
float cal_ec_std[] = { 84.43, 1452.93, 13258.08 };

float ec_slope = 1.0;
float ec_intercept = 0.0;

float loadcell_raw[] = { 
  2611734, 2619282, 2628194, 2636986, 2654585, 
  2698371, 2785731, 2872980, 3047255, 3307728, 
  3483624, 3918092, 4356299 
};
float loadcell_weight[] = { 
  0.0, 1.0, 2.0, 3.0, 5.0, 
  10.0, 20.0, 30.0, 50.0, 80.0, 
  100.0, 150.0, 200.0 
};

// ================= CONSTANTS =================
const unsigned long PENDING_DURATION_SEC = 10;
const unsigned long STRICT_LOG_FILE_RETRY_MS = 5000;
const unsigned long REC_QUEUE_WAIT_MS = 100;
const uint32_t SD_LOCK_TIMEOUT_MS = 1000;
const unsigned long SD_RETRY_MS = 5000;
const char* SYSTEM_LOG_PATH = "/autotttoutput/msatlog.txt";
const size_t SYSTEM_LOG_MAX_BYTES = 256000;
const bool ENABLE_METRIC_LOG = true;
const char* METRIC_LOG_PATH = "/autotttoutput/msatmetric.txt";
const unsigned long METRIC_LOG_COOLDOWN_MS = 60000;
const size_t SD_WRITE_QUEUE_MAX = 500;
const size_t SD_QUEUE_LINE_MAX = 192;
const size_t METRIC_QUEUE_WARN = 50;
const size_t METRIC_QUEUE_ERR = 200;
const unsigned long STOP_FLUSH_TIMEOUT_MS = 3000;
const unsigned long METRIC_SD_WRITE_WARN_MS = 250;
const unsigned long METRIC_SD_WRITE_ERR_MS = 500;
const unsigned long METRIC_SENSOR_LAG_MS = 200;
const unsigned long WEB_STALL_WARN_MS = 1000;
const unsigned long SYNC_TIMEOUT_MS = 10000;
const unsigned long BUTTON_COOLDOWN_MS = 500;
#define BOOT_CHECK_DELAY_MS 2000 
#define TCS_GAIN_SETTING TCS34725_GAIN_4X 
#define TCS_INTEGRATION_TIME TCS34725_INTEGRATIONTIME_24MS
const unsigned long STATUS_CHECK_INTERVAL = 5000;
const int AUTO_STOP_AVG_SAMPLES = 10;
const int AUTO_STOP_HOLD_COUNT = 3;
const float AUTO_STOP_MAX_WEIGHT_STEP_G_PER_SEC = 20.0f;
const float AUTO_STOP_MIN_WEIGHT_STEP_G = 1.0f;
const float AUTO_STOP_GUIDE_MAX_DEVIATION_G = 2.0f;
const float AUTO_STOP_GUIDE_SLOPE_ALPHA = 0.25f;
const float AUTO_STOP_GUIDE_MAX_SLOPE_G_PER_SEC = 20.0f;
const float SENSOR_EC_EMA_ALPHA = 0.22f;
const float SENSOR_PH_EMA_ALPHA = 0.20f;
const float SENSOR_PH_RUN_MAX_STEP_PER_SEC = 6.00f;
const float SENSOR_PH_RUN_SPIKE_REJECT_DELTA = 2.50f;
const float SENSOR_PH_RUN_BURST_TRIGGER_DELTA = 0.60f;
const int SENSOR_PH_RUN_BURST_HOLD_CYCLES = 30;
const float SENSOR_PH_RUN_BURST_MAX_STEP_PER_SEC = 18.00f;
const float SENSOR_PH_RUN_BURST_ALPHA = 0.45f;
const float SENSOR_PH_RUN_EMI_OFFSET_ALPHA = 0.22f;
const float SENSOR_PH_RUN_EMI_RELEASE_ALPHA = 0.35f;
const float SENSOR_PH_RUN_EMI_OFFSET_MAX = 0.65f;
const float SENSOR_PH_BUMP_THRESHOLD_DELTA = 0.50f;
const int SENSOR_PH_BUMP_THRESHOLD_COUNT = 3;
const float SENSOR_TEMP_EMA_ALPHA = 0.25f;
const float SENSOR_RGB_EMA_ALPHA = 0.30f;
const float SENSOR_EC_MAX_STEP_US_PER_SEC = 260.0f;
const float SENSOR_EC_MIN_STEP_US = 8.0f;
const float SENSOR_EC_SPIKE_REJECT_US = 180.0f;
const float SENSOR_EC_ADAPT_TRIGGER_DELTA_US = 52.0f;
const float SENSOR_EC_ADAPT_RELEASE_DELTA_US = 34.0f;
const int SENSOR_EC_ADAPT_HOLD_CYCLES = 3;
const float SENSOR_EC_ADAPT_EMA_ALPHA = 0.33f;
const float SENSOR_EC_ADAPT_MAX_STEP_US_PER_SEC = 420.0f;
const float SENSOR_EC_ADAPT_SPIKE_REJECT_US = 250.0f;
const float SENSOR_EC_BUMP_THRESHOLD_DELTA_US = 90.0f;
const int SENSOR_EC_BUMP_THRESHOLD_COUNT = 3;
// EC start-of-RUN settling: a real physical/electrical transient happens
// in the first few seconds after dosing begins (probe boundary layer,
// pump turn-on coupling, initial salt formation). It can be wider than
// median7 can reject. For this window, clamp per-sample EC change to a
// small fraction of the current value so a multi-sample spike cannot
// inflate ecFiltered. After the window, no clamp -> EP stays sharp.
const int SENSOR_EC_RUN_SETTLE_CYCLES = 20;        // ~5 s @250 ms cadence
const float SENSOR_EC_RUN_SETTLE_MAX_FRAC = 0.05f; // <=5%/sample during settle
const float SENSOR_EC_RUN_SETTLE_MIN_STEP_US = 10.0f;
// Anomaly-skip: protects against EC transients that are too wide for
// median9 (e.g. Succinic ~5 raw samples). If the median-filtered value
// suddenly deviates from the filter state by > 20% (or > 300 uS), freeze
// ecFiltered for up to N samples; if the deviation persists past N (real
// fast change), accept it. The 20% threshold is far above any per-sample
// delta at the titration inflection (typically <2% of mid-titration EC),
// so the EP is never frozen. Works any time during RUN, not just startup.
const float SENSOR_EC_ANOMALY_FRAC = 0.20f;        // 20% deviation triggers
const float SENSOR_EC_ANOMALY_MIN_DELTA_US = 300.0f; // absolute floor
const int SENSOR_EC_ANOMALY_SKIP_MAX = 12;         // ~3 s max freeze
const float SENSOR_TEMP_VALID_MIN_C = -55.0f;
const float SENSOR_TEMP_VALID_MAX_C = 125.0f;
const float SENSOR_TEMP_POR_INVALID_C = 85.0f;
const float SENSOR_TEMP_POR_EPS_C = 0.01f;
const float DISPLAY_WEIGHT_GUIDE_ALPHA = 0.25f;
const float DISPLAY_WEIGHT_MAX_DEVIATION_G = 1.5f;
const float DISPLAY_WEIGHT_MAX_SLOPE_G_PER_SEC = 25.0f;
const float DISPLAY_WEIGHT_RUN_MAX_DEVIATION_G = 4.0f;
const float DISPLAY_WEIGHT_RUN_MAX_SLOPE_G_PER_SEC = 80.0f;

const unsigned long SENSOR_IDLE_MS = 250;
const unsigned long SENSOR_PENDING_MS = 200;
const unsigned long SENSOR_RUNNING_MS = 50;
const unsigned long SENSOR_RINSE_MS = 300;
const unsigned long SENSOR_REC_MS = 150;

const unsigned long EC_IDLE_MS = 1000;
const unsigned long EC_PENDING_MS = 500;
const unsigned long EC_RUNNING_MS = 250;
const unsigned long EC_RINSE_MS = 1000;
const unsigned long EC_REC_MS = 250;

const unsigned long LCD_IDLE_MS = 500;
const unsigned long LCD_PENDING_MS = 100;
const unsigned long LCD_RUNNING_MS = 200;
const unsigned long LCD_RINSE_MS = 500;
const unsigned long LCD_REC_MS = 200;

const unsigned long LOG_IDLE_MS = 10000;
const unsigned long LOG_PENDING_MS = 2000;
const unsigned long LOG_RUNNING_MS = 500;
const unsigned long LOG_RINSE_MS = 5000;
const unsigned long LOG_REC_MS = 500;

// File list and rebuild constants (removed from implementation, but kept for compatibility)
const unsigned long FILE_LIST_CACHE_MAX = 2000;
const unsigned long FILE_LIST_REFRESH_MS = 10000;
const unsigned long AUTO_REBUILD_MIN_UPTIME_MS = 10000;
const unsigned long REBUILD_RETRY_BACKOFF_MS = 30000;

const unsigned long TIME_SYNC_RETRY_MS = 300000;
const char* INDEX_FILE_PATH = "/autotttoutput/_index.txt";
const char* FW_VERSION = "V.Y2026.88.17";
const char* FW_BUILD_ID = "MSAT-V.Y2026.88.17";

// ================= GLOBAL OBJECTS =================
AsyncWebServer server(80);
AsyncWebSocket ws("/ws");
OneWire oneWire(ONE_WIRE_BUS);
DallasTemperature sensors(&oneWire);
HX711 scale;
Adafruit_ADS1115 ads;
Adafruit_TCS34725 tcs = Adafruit_TCS34725(TCS_INTEGRATION_TIME, TCS_GAIN_SETTING); 
ModbusMaster node; 
RTC_DS3231 rtc; 
LiquidCrystal_I2C lcd(0x27, 16, 2);

TaskHandle_t TaskSensors;
TaskHandle_t TaskSDWriter;

struct SDQueueItem {
  char data[SD_QUEUE_LINE_MAX];
};

std::deque<SDQueueItem> sdWriteQueue;
SemaphoreHandle_t sdQueueMutex = NULL;
SemaphoreHandle_t sdCardMutex = NULL;
unsigned long lastSdRetryMs = 0;
SemaphoreHandle_t fileListMutex = NULL;
std::vector<String> cachedFileList;
bool cachedFileListTruncated = false;
unsigned long lastFileListUpdateMs = 0;
volatile bool fileListRefreshRequested = false;
volatile bool fileListRefreshInProgress = false;
volatile uint32_t fileListGeneration = 0;
volatile bool rebuildIndexRequested = false;
volatile bool rebuildIndexInProgress = false;
volatile uint32_t rebuildProgress = 0;
volatile unsigned long rebuildStartedMs = 0;
volatile unsigned long lastRebuildFailMs = 0;
String rebuildOwnerIP = "";
String rebuildStatusText = "IDLE";
volatile bool manifestRebuildRequested = false;
volatile bool manifestRebuildInProgress = false;

// ================= CLIENT CONNECTION TRACKING =================
#define MAX_CLIENTS 2
#define CLIENT_TIMEOUT_SEC 300  
#define ADMIN_PASSWORD "CHANGE_ME_BEFORE_USE"   // <-- EDIT ME (admin action password)

struct ClientInfo {
  String ipAddress;
  String macAddress;
  unsigned long connectedTime;
  unsigned long lastActivityTime;
  String userAgent;
  String deviceName;
};
std::vector<ClientInfo> connectedClients;
SemaphoreHandle_t clientListMutex = NULL;

// ================= SHARED VARIABLES =================
volatile int currentState = 0;
volatile bool isLogging = false;
volatile bool stopFlushInProgress = false;
volatile bool logFileCreatePending = false;
volatile bool syncMode = false;
unsigned long lastSyncHeartbeatMs = 0;

// ================= WIFI MONITORING =================
unsigned long lastWifiCheck = 0;
unsigned long lastWifiReconnectAttempt = 0;
const unsigned long WIFI_CHECK_INTERVAL_MS = 10000;      // Check every 10 seconds (detect disconnection faster)
const unsigned long WIFI_RECONNECT_COOLDOWN_MS = 60000;  // Wait 60s between reconnect attempts (slow routers need longer)
const unsigned long WIFI_RECONNECT_TIMEOUT_MS = 60000;   // Allow up to 60s for one reconnection attempt
volatile bool wifiConnected = false;
volatile bool wifiReconnecting = false;
volatile bool wifiEverConnected = false;
volatile bool webServerStarted = false;
volatile bool twdtInitialized = false;  // Track if TWDT init succeeded to prevent crashes
unsigned long syncUntilMs = 0;
unsigned long syncLastActivityMs = 0;
String currentLogFileName = "";
String lastCompletedRecFileName = "";
String lastCompletedStopReason = "NONE";
volatile int lcdPage = 0; 
String controlClientIP = "";
String adminClientIP = "";
String lastWebCommandIP = "";
unsigned long startLimiterUntilMs = 0;
bool useExternalWebServer = false;
const char* PC_WEB_SERVER_IP = "192.168.1.199";
const int PC_WEB_SERVER_PORT = 80;

volatile int autoStopMode = 1;
volatile float autoStopWeightTarget = 85.0;
volatile unsigned long autoStopTimeTarget = 300;
volatile int runAutoStopMode = 0;
volatile float runAutoStopWeightTarget = 0.0;
volatile unsigned long runAutoStopTimeTarget = 0;
String customFilename = "";
unsigned long recordingStartTime = 0;
unsigned long lastLogCreateAttemptMs = 0;
uint64_t runLogEpochBaseMs = 0;
unsigned long runLogSampleIndex = 0;
unsigned long runLogStepMs = LOG_RUNNING_MS;
bool runLogClockArmed = false;
String lastStopReason = "NONE";
volatile int lastCommandSource = 2;
// ===== Web Command Flags =====
volatile bool webCmdToggle = false;
volatile bool webCmdRinse = false;
volatile bool webCmdRecord = false;
volatile bool webCmdTare = false;

float weightLossAvg = 0.0;
float weightLossSamples[AUTO_STOP_AVG_SAMPLES];
int weightLossSampleCount = 0;
int weightLossSampleIndex = 0;
int autoStopHitCount = 0;
float weightLossGuide = 0.0f;
float weightLossGuideSlope = 0.0f;
bool weightLossGuideInit = false;

bool timeSynced = false;
unsigned long lastTimeSyncMs = 0;
bool st_ads = false, st_rgb = false, st_temp = false, st_scale = false, st_sd = false, st_ec = false, st_rtc = false;
unsigned long lastScaleSuccess = 0;

volatile float currentPH = 0.0, currentVolt = 0.0, currentEC = 0.0, currentTemp = 0.0;
volatile float currentGrossWeight = 0.0, tareOffset = 0.0, currentNetWeight = 0.0, currentNetWeightRaw = 0.0;
volatile int currentR = 0, currentG = 0, currentB = 0, currentC = 0;
bool phFilterInit = false, ecFilterInit = false, tempFilterInit = false, rgbFilterInit = false;
float phRawHist[3] = {0.0f}, ecRawHist[9] = {0.0f}, tempRawHist[3] = {0.0f};
int phRawHistCount = 0, phRawHistIndex = 0, ecRawHistCount = 0, ecRawHistIndex = 0, ecSpikeGuardCount = 0, tempRawHistCount = 0, tempRawHistIndex = 0;
int rgbRawHistR[3] = {0}, rgbRawHistG[3] = {0}, rgbRawHistB[3] = {0};
int rgbRawHistCount = 0, rgbRawHistIndex = 0;
float phFiltered = 0.0f, ecFiltered = 0.0f, tempFiltered = 0.0f, rgbFilteredR = 0.0f, rgbFilteredG = 0.0f, rgbFilteredB = 0.0f;
int phBumpConfirmCounter = 0, ecBumpConfirmCounter = 0;
float phLastNonRunning = 0.0f; bool phLastNonRunningValid = false;
float phLastNonRunningVolt = 0.0f; bool phLastNonRunningVoltValid = false;
float phRunVoltOffset = 0.0f; bool phRunVoltOffsetInit = false;
int phRunBurstCycles = 0;
bool displayWeightFilterInit = false; float displayWeightGuide = 0.0f; float displayWeightGuideSlope = 0.0f;
float w0_sum = 0.0, w0_sum_sq = 0.0, ph0_sum = 0.0, temp0_sum = 0.0, ec0_sum = 0.0;
long r0_sum = 0, g0_sum = 0, b0_sum = 0; int w0_count = 0, countdownTime = 0;
unsigned long pendingStartTime = 0;
float W0 = 0.0, W0_SD = 0.0, weightLoss = 0.0, PH0 = 0.0, Temp0 = 0.0, EC0 = 0.0;
int Red0 = 0, Green0 = 0, Blue0 = 0; float recStartWeight = 0.0f;
unsigned long lastBtn1Action = 0, lastBtn2Action = 0, lastBtn3Action = 0, btn1PressStart = 0, btn2PressStart = 0;
bool btn1HoldPending = false, btn2HoldPending = false;
const unsigned long STOP_HOLD_MS = 1500; const unsigned long RINSE_HOLD_MS = 300;
int lastRelayPinState = HIGH;

const char* ntpServer = "pool.ntp.org";
const long gmtOffset_sec = 25200;
const int daylightOffset_sec = 0;
const char* TZ_INFO = "UTC-7";

bool ensureSDReady();
bool tryLockSD(uint32_t timeoutMs);
void unlockSD();
String getSyncStatusJSON();

uint64_t getFileModifiedTimeSafe(File &f) {
  time_t ts = f.getLastWrite();
  if (ts <= 0) return 0;
  return (uint64_t)ts;
}
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
void loop() { 
  // WiFi Health Check & Auto Reconnect every 10 seconds
  if (millis() - lastWifiCheck >= WIFI_CHECK_INTERVAL_MS) {
    lastWifiCheck = millis();
    checkAndReconnectWiFi();
  }

  if (syncMode && !rebuildIndexInProgress && (millis() - lastSyncHeartbeatMs > SYNC_TIMEOUT_MS)) {
    syncMode = false;
    ws.enable(true);
    Serial.println(">> SYNC MODE TIMEOUT: Auto-exiting (WebSocket enabled)");
  }
  
  // Send WebSocket Broadcast with adaptive frequency
  // Reduces network load when multiple devices connected
  static unsigned long lastWsBroadcast = 0;
  static unsigned long lastWsCleanup = 0;
  // User-configurable WS interval by state group
  unsigned long broadcastInterval = WS_REFRESH_IDLE_MS;
  if (currentState == 2 || currentState == 4) {
    broadcastInterval = WS_REFRESH_RUN_REC_MS;
  } else if (currentState == 1 || currentState == 3) {
    broadcastInterval = WS_REFRESH_PENDING_RINSE_MS;
  }
  
  if (!syncMode && (millis() - lastWsBroadcast > broadcastInterval)) {
    lastWsBroadcast = millis();
    // Guard: skip broadcast if heap is critically low to prevent malloc panic
    // (heap can fragment after long runs with many SD queue allocations)
    if (ws.count() > 0 && ESP.getFreeHeap() > 8192) {
      // REVERTED to the library's own synchronized broadcast. The previous
      // per-client loop over ws.getClients() from loop() raced the AsyncTCP
      // task: if a client disconnected mid-iteration the client list was
      // mutated under us -> iterator invalidation -> heap corruption ->
      // ESP32 panic/reboot loop -> dashboard unreachable. ws.textAll() with
      // the availableForWriteAll() guard is the library-safe path. (WL
      // dashboard lag is the lesser evil vs. the web crashing; revisit with
      // a snapshot-copy approach if the lag must be fixed.)
      if (ws.availableForWriteAll()) {
        ws.textAll(getTelemetryJSON("-"));
      }
    }
  }
  
  // Separate cleanup from broadcast to reduce blocking
  if (millis() - lastWsCleanup > 2000) {  // 2s cleanup to release stale client frame buffers sooner
    lastWsCleanup = millis();
    ws.cleanupClients();
  }

  applyRelayState();
  if (!timeSynced && wifiConnected) {
    if (millis() - lastTimeSyncMs >= TIME_SYNC_RETRY_MS) { timeSynced = syncTimeFromNtp(); lastTimeSyncMs = millis(); }
  }
  
  // Buttons handling
  if (flagBtn1) { 
    flagBtn1 = false; 
    if (currentState == 0) { if (millis() - lastBtn1Action > BUTTON_COOLDOWN_MS) { lastBtn1Action = millis(); lastCommandSource = 1; toggleSystem(); } } 
    else { btn1PressStart = millis(); btn1HoldPending = true; }
  }
  if (btn1HoldPending) {
    if (digitalRead(BUTTON1_PIN) == LOW) {
      if (millis() - btn1PressStart >= STOP_HOLD_MS) { btn1HoldPending = false; if (millis() - lastBtn1Action > BUTTON_COOLDOWN_MS) { lastBtn1Action = millis(); lastCommandSource = 1; toggleSystem(); } }
    } else { btn1HoldPending = false; }
  }
  
  if (flagBtn2) { flagBtn2 = false; btn2PressStart = millis(); btn2HoldPending = true; }
  if (btn2HoldPending) {
    if (digitalRead(BUTTON2_PIN) == LOW) {
      if (millis() - btn2PressStart >= RINSE_HOLD_MS) { btn2HoldPending = false; if (millis() - lastBtn2Action > BUTTON_COOLDOWN_MS) { lastBtn2Action = millis(); lastCommandSource = 1; toggleRinse(); } }
    } else { btn2HoldPending = false; }
  }
  
  if (flagBtn3) { flagBtn3 = false; if (millis() - lastBtn3Action > 200) { lastBtn3Action = millis(); lcdPage++; int maxPage = (currentState == 2) ? 6 : 5; if(lcdPage > maxPage) lcdPage = 0; } }
  // Process web commands here in loop() to prevent Async Task stall causing board reset
  if (webCmdToggle) { webCmdToggle = false; toggleSystem(); }
  if (webCmdRinse)  { webCmdRinse = false; toggleRinse(); }
  if (webCmdRecord) { webCmdRecord = false; toggleRecord(); }
  if (webCmdTare)   { 
    webCmdTare = false; 
    tareOffset = currentGrossWeight; currentNetWeightRaw = currentGrossWeight - tareOffset; currentNetWeight = currentNetWeightRaw;
    displayWeightGuide = currentNetWeightRaw; displayWeightGuideSlope = 0.0f; displayWeightFilterInit = true;
  }
  delay(1); 
}

void TaskSensorsCode(void * pvParameters) {
  unsigned long lastStep = 0, lastLog = 0, lastEC = 0, lastStatus = 0, lastLCD = 0; unsigned long lastLoopMs = 0; unsigned long lastSerial = 0;
  static bool hasLastValidNetWeight = false; static float lastValidNetWeight = 0.0f; static int lastStateForLogSync = -1;
  static int weightRejectCount = 0;
  static int ecAdaptiveHoldCycles = 0;
  static int ecRunSettleCycles = 0;
  static int ecAnomalySkips = 0;
  static unsigned long lastCountdownUpdate = 0;  // Add countdown update timer
  
  bool wdtRegistered = false;
  if (twdtInitialized) {
    esp_err_t wdtAddErr = esp_task_wdt_add(NULL); // Register this task with watchdog supervision
    wdtRegistered = (wdtAddErr == ESP_OK || wdtAddErr == ESP_ERR_INVALID_STATE);
    if (!wdtRegistered) {
      Serial.printf("[WDT] Warning: TaskSensors add failed (%d)\n", (int)wdtAddErr);
    }
  }

  for(;;) {
    unsigned long now = millis();
    if (syncMode) {
      if (now - lastLCD >= 400) {
        lastLCD = now;
        printCentered("- SYNC BY PC -", 0);
        printCentered("WAIT...", 1);
      }
      if (wdtRegistered) esp_task_wdt_reset();
      vTaskDelay(pdMS_TO_TICKS(50));
      continue;
    }
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

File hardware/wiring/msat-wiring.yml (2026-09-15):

# MSAT — Multi-Sensor Automatic Titrator
# Wiring source-of-truth for WireViz, as built.
# GPIO numbers match the #defines in msat-firmware/msat-firmware.ino; supply
# rails and the I²C level converter are taken from the built unit and agree
# with Supplementary Table S2 of the paper. Render with:
#   wireviz msat-wiring.yml
#
# ⚠ GPIO2 and GPIO15 are ESP32 strapping pins. Disconnect during flashing.
# ⚠ The LCD runs at 5 V and is wired straight to GPIO32/33 (as built). For a new
#   build, put it on the HV side of the level converter or remove its pull-ups.

metadata:
  title: MSAT — ESP32-WROOM-32 wiring (as built)
  description: >
    Multi-Sensor Automatic Titrator. 12 V supply with two LM2596 bucks (5 V bus
    and pump supply). ESP32 talks to four I²C devices: ADS1115/pH at 5 V through
    an LLC-4CH-I2C level converter, TCS34725/colour and DS3231 RTC at 3.3 V, and
    a 16×2 LCD at 5 V. One 1-Wire DS18B20, HX711 load cell, MAX485 → Modbus EC
    transmitter, microSD on VSPI, a pump relay, and three push buttons.

options:
  color_mode: full
  bgcolor: WH
  fontname: Arial

# ============================================================
# CONNECTORS (one per module)
# ============================================================
connectors:

  PSU12V:
    type: 12 V / 5 A (60 W) switching supply
    subtype: main supply
    color: BK
    pinlabels: ["V+ 12V", "V- GND"]

  BUCK1:
    type: LM2596 #1
    subtype: 12 V → 5 V bus (lock at 5 V)
    color: BK
    pinlabels: ["IN+", "IN-", "OUT+ 5V", "OUT- GND"]

  BUCK2:
    type: LM2596 #2
    subtype: 12 V → pump supply (~7.5 V)
    color: BK
    pinlabels: ["IN+", "IN-", "OUT+ PUMP", "OUT- GND"]

  ESP32:
    type: ESP32-WROOM-32 (38-pin)
    subtype: MCU
    color: WH
    pinlabels: [3V3, GND, VIN 5V, GPIO32 SDA, GPIO33 SCL,
                GPIO2 DE/RE, GPIO16 RX, GPIO17 TX,
                GPIO4 1-Wire,
                GPIO25 HX-DT, GPIO26 HX-SCK,
                GPIO5 SD-CS, GPIO18 SD-SCK, GPIO19 SD-MISO, GPIO23 SD-MOSI,
                GPIO13 RELAY,
                GPIO27 BTN1, GPIO14 BTN2, GPIO15 BTN3]

  LLC:
    type: LLC-4CH-I2C level converter
    subtype: bidirectional 3.3 V ↔ 5 V
    color: BU
    pinlabels: [LV 3V3, LV GND, LV1 SCL, LV2 SDA, HV 5V, HV GND, HV1 SCL, HV2 SDA]

  ADS1115:
    type: ADS1115 — pH ADC
    subtype: I²C 0x48 (via level converter)
    color: BU
    pinlabels: [VDD 5V, GND, SCL, SDA, AIN0 (pH PO), AIN1, AIN2, AIN3]

  PHBOARD:
    type: E-201-C pH electrode + analog interface board
    subtype: analog out
    color: BU
    pinlabels: [VCC 5V, GND, PO]

  GY33:
    type: TCS34725 — colour
    subtype: I²C 0x29
    color: BU
    pinlabels: [VIN 3V3, GND, SCL, SDA, INT, LED]

  DS3231:
    type: DS3231 RTC
    subtype: I²C 0x68
    color: BU
    pinlabels: [VCC 3V3, GND, SCL, SDA, SQW, 32K]

  LCD1602:
    type: LCD 16×2 + PCF8574 backpack
    subtype: I²C 0x27, 5 V
    color: BU
    pinlabels: [VCC 5V, GND, SCL, SDA]

  DS18B20:
    type: DS18B20 — temperature probe
    subtype: 1-Wire
    color: GN
    pinlabels: [VDD 3V3, GND, DQ]
    notes: 4.7 kΩ pull-up resistor from DQ to 3V3

  HX711:
    type: HX711 — load-cell amplifier
    subtype: load cell
    color: YE
    pinlabels: [VCC 5V, GND, DT, SCK, E+, E-, A+, A-]

  MAX485:
    type: MAX485 — RS-485 transceiver
    subtype: Serial2 9600 8N1
    color: OG
    pinlabels: [VCC 5V, GND, RO, RE, DE, DI, A, B]

  ECMETER:
    type: MI-Water-EC485 EC transmitter (Modbus RTU)
    subtype: slave id 1, holding reg 0x0000
    color: OG
    pinlabels: ["V+ 12V (red)", "GND (black)", "A (yellow)", "B (blue)"]

  SDCARD:
    type: microSD card module
    subtype: SPI (VSPI)
    color: VT
    pinlabels: [VCC 5V, GND, CS, SCK, MISO, MOSI]

  RELAY:
    type: Relay 1-ch 5V (active-high)
    subtype: pump dosing
    color: RD
    pinlabels: [VCC 5V, GND, IN, COM, "NO", "NC"]

  PUMP:
    type: Peristaltic pump 12 V / 3 W DC
    subtype: run at ~7.5 V
    color: RD
    pinlabels: ["Red (+)", "Black (-)"]

  BTN1:
    type: Push button 1 (titration)
    color: GY
    pinlabels: [GPIO27, GND]

  BTN2:
    type: Push button 2 (rinse)
    color: GY
    pinlabels: [GPIO14, GND]

  BTN3:
    type: Push button 3 (record, strapping pin)
    color: GY
    pinlabels: [GPIO15, GND]
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

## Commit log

2026-05-21 Initial public release: MSAT (Multi-Sensor Automatic Titrator)
    ESP32 firmware, Python data analyzer, and WiFi sync tool for a low-cost
    automatic acid-base titrator (pH/EC/colour/temperature + gravimetric titrant).
    Copyright (c) 2026 Burapha University. Inventor: Teeranan Nongnual.
    Petty Patent pending No. 2603001145 (filed 2026-05-12).
    License: PolyForm Noncommercial 1.0.0 (code) / CC BY-NC 4.0 (docs, hardware, data).
    [Autotitration-Components-Wiring-v20260114-v61.xlsx, autotitration.fzz]
2026-05-22 Rename Fritzing wiring files to msat-* scheme + add firmware-exact WIRING.md
    - autotitration.fzz -> msat-wiring.fzz; xlsx -> msat-wiring-components.xlsx
    - "Frizting modules/" -> "fritzing-parts/" (fix typo)
    - Add hardware/wiring/WIRING.md: connection table derived from
    msat-firmware.ino, plus sketch fix checklist and parts-to-download list
    - Update hardware/README.md file references
    [msat-wiring-components.xlsx, msat-wiring.fzz]
2026-05-22 Update analyzer: XO- export prefix, Config card (Save/Load/Clear), X-max-bounded analysis
    - Save button now exports XO-<name>.* and XO-<name>-config.txt; dialog lists
    the config sidecar and reports 5 files saved
    - New Config card: Save Config (config-only), Load Config, Clear Config
    (reset settings + clear EP results, keep file loaded), with status label
    - Run Analysis now clips EP/peak finding to the X Maximum range
2026-05-22 analyzer: move Save Config under Save IMG & Config in Export Tools
    Config-only save now lives beneath the image-save button; the Config card
    keeps Load Config + Clear Config.
2026-05-22 hardware: add vector wiring schematic + Fritzing part download links
    - msat-wiring-schematic.svg: firmware-exact wiring diagram (ESP32 + all
    modules, colour-coded buses) for publication / quick reference
    - WIRING.md: direct .fzpz download links for the missing modules
    (DS3231, LCD1602-I2C, microSD, relay, MAX485, pH BNC) + figure note
    - README: list the new schematic + updated WIRING.md description
2026-05-23 hardware: add WireViz harness diagram (pin-by-pin, with BOM)
    - msat-wiring.yml: WireViz source of truth, derived from msat-firmware.ino
    pin map (I2C 32/33, RS-485 2/16/17, 1-Wire 4, HX711 25/26, VSPI CS5,
    relay 13, buttons 27/14/15)
    - Rendered .svg/.png/.html/.bom.tsv: harness-style diagram showing every
    connector pin and every wire colour, plus interactive BOM
    - WIRING.md + hardware/README.md: document the new files and how to
    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
    [msat-wiring.bom.tsv]
2026-06-05 docs: credit co-inventors; analyzer: refresh to latest build
    - README, NOTICE, LICENSE, CITATION.cff: add six co-inventors alongside inventor/developer Teeranan Nongnual
    - analyzer/msat-datanal.py: update to current working version
2026-06-11 licensing: relicense to open source (Apache-2.0 + CERN-OHL-S v2 + CC BY 4.0)
    Replaces PolyForm Noncommercial 1.0.0 + CC BY-NC 4.0. Code: Apache-2.0; hardware design files: CERN-OHL-S v2 (new LICENSE-hardware); docs/images/data: CC BY 4.0. Petty patent 2603001145 (Burapha University) is now disclosed and licensed under these licenses' patent grants (university IP office approved), not reserved. Updated NOTICE, README, CITATION.cff, and all source-file/README/SVG license headers.
    [msat-firmware.ino]
2026-09-12 data+docs: release the runs behind the paper figures, add the probe-lid STL
    sample-data now holds the exact nine runs from which the manuscript figures were
    produced, so every published trace can be regenerated from the repository. The
    previous set overlapped with the figures in one file only (KHP-3). Four of the
    replaced runs also came from an earlier firmware build: they logged at 1.3-1.5 Hz
    rather than 2 Hz, used a 12-column layout without SampleIndex, and had 43-49 % of
    their pH samples clamped at 14.00 by the extrapolation limit. All nine current
    files are 2.00 Hz, 13-column, with no clamping.
    Also in this commit:
    - hardware/3d-print/: the probe-mounting lid STL (binary, 710 triangles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
    [msat-probe-lid.stl]
2026-09-15 hardware: document the wiring as built
    The wiring files described every I2C device on a 3.3 V bus with no level
    converter, one buck converter, and a mains-powered pump. The built unit, and
    Supplementary Tables S1 and S2 of the paper, differ:
    - ADS1115 runs at 5 V behind an LLC-4CH-I2C 3.3 V <-> 5 V level converter
    - LCD 16x2 (PCF8574) runs at 5 V, wired directly to GPIO32/33
    - 12 V / 5 A supply feeds two LM2596 bucks (5 V bus, pump at ~7.5 V) and the
    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
    [msat-wiring-components.xlsx, msat-wiring.bom.tsv]
2026-09-15 hardware/3d-print: describe the lid openings and the color-sensor mount
    The lid holds the pH electrode, the conductivity electrode (hexagonal seat for
    its gland nut), the DS18B20 probe and the titrant delivery tube. The TCS34725
    color sensor is not part of the lid and has no printed mount: it is taped to
    the inner wall of the expanded-polystyrene enclosure, pressed against the
    beaker, with a white LED panel on the opposite side shining through the
    solution toward it.
    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
